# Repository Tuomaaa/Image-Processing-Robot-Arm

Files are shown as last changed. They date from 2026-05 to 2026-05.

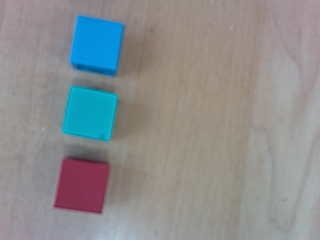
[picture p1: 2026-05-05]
Image&Videos/TestImage1.jpg

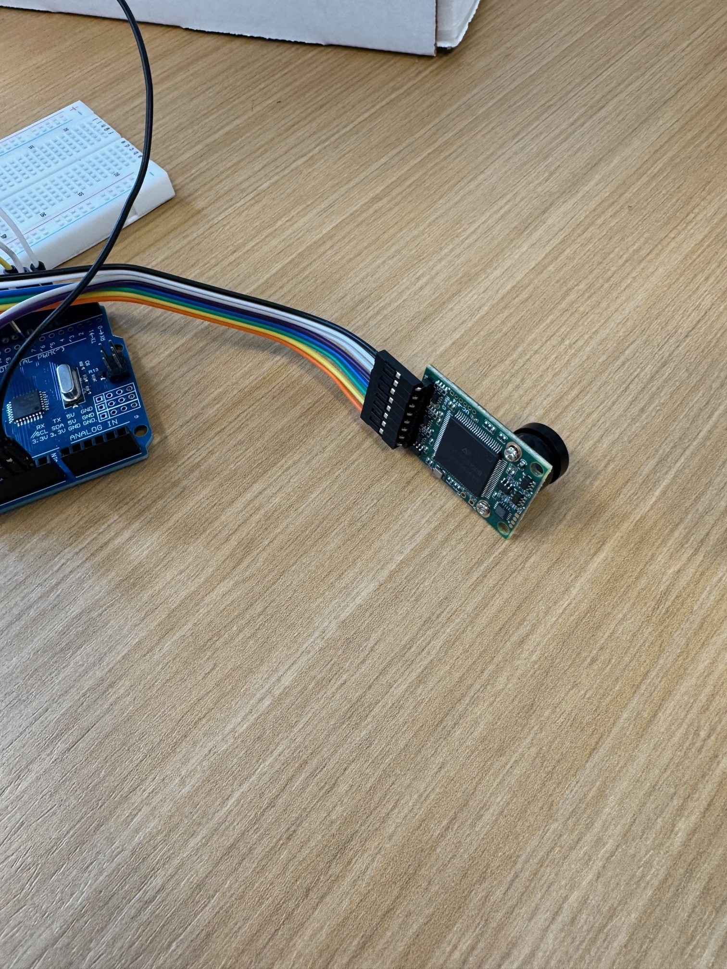
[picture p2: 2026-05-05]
Wiring/2.jpg

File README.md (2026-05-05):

This is 3d printed robot arm content for the image processing course
to create a block sorting project using MATLAB and an ArduCam. The arms was inspired by the following printable. 
https://www.printables.com/model/818975-compact-robot-arm-arduino-3d-printed/comments
Build Some Stuff8
Build Some Stuff
@buildsomestf_192457
Detailed Assembly Tutorial: https://youtu.be/AIsVlgopqJc Designed by Kelton.
https://www.youtube.com/watch?v=AIsVlgopqJc

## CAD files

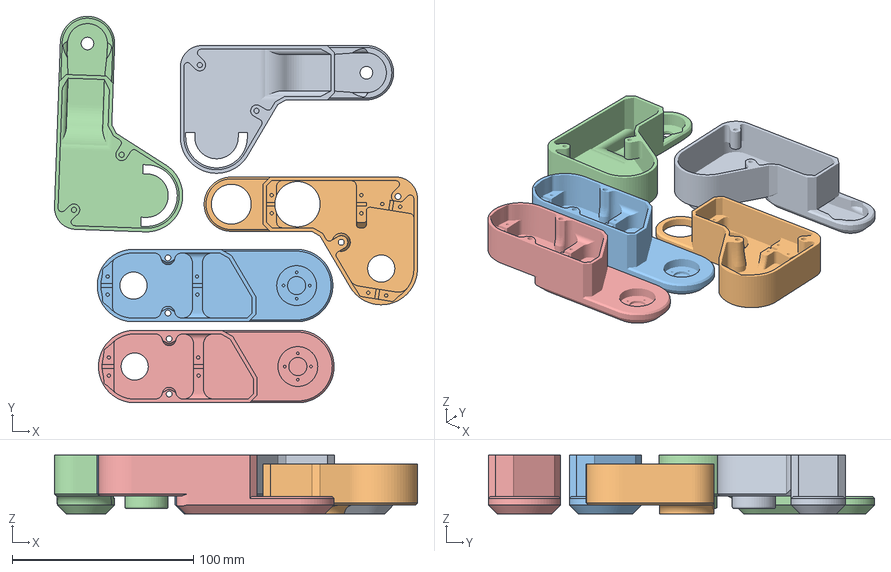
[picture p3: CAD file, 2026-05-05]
CAD/MainBody.3mf
200.3 x 213.1 x 32.5 mm
Forearm2.stl x 2
Forearm.stl
Upperarm.stl x 2

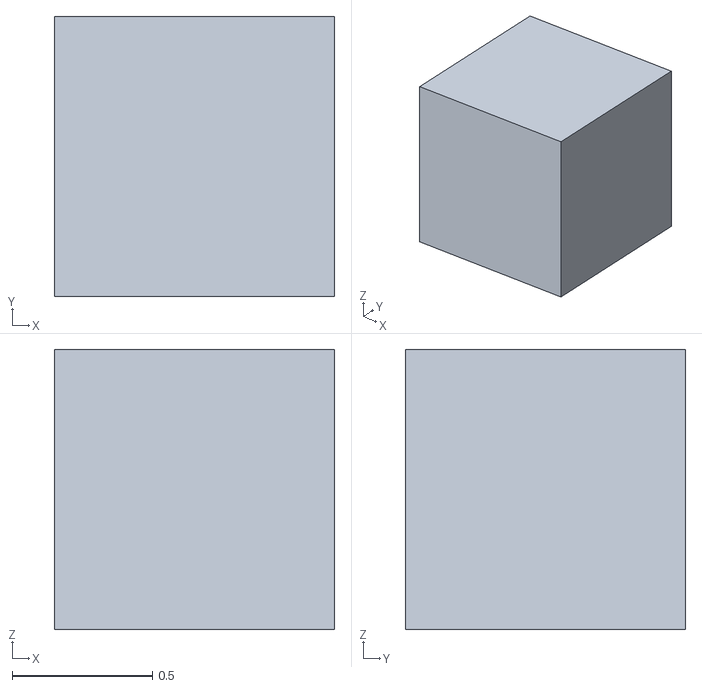
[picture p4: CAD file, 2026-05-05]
CAD/Monay_Square.stl
1.00 x 1.00 x 1.00

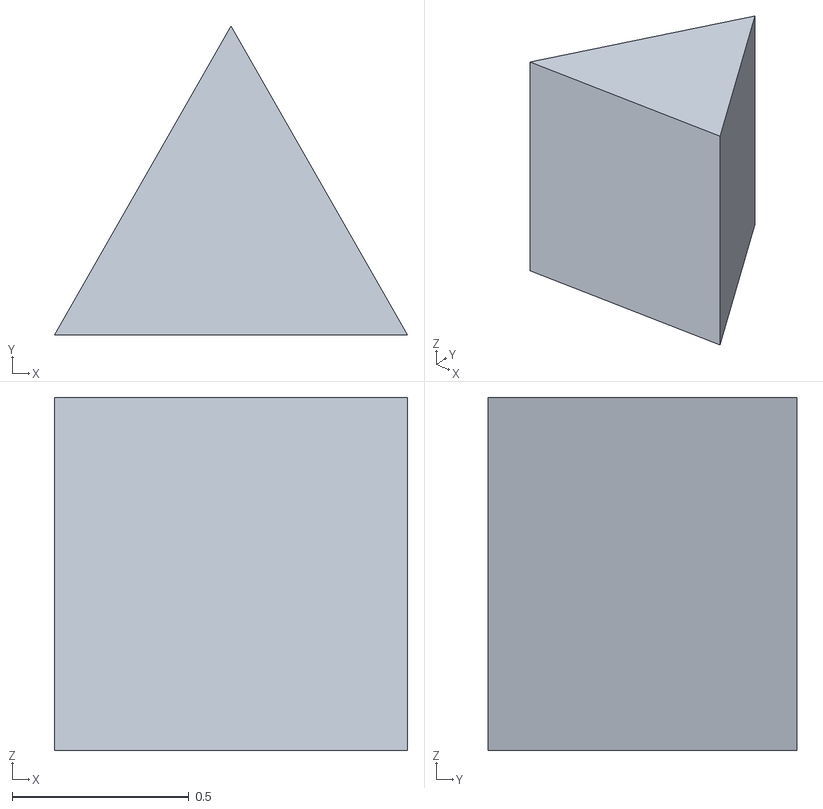
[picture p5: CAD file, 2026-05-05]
CAD/Monay_Triangle.stl
1.00 x 0.875 x 1.00

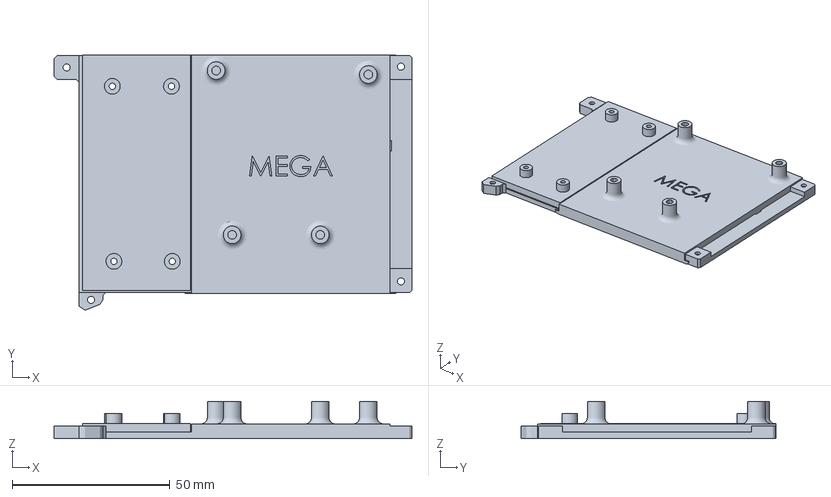
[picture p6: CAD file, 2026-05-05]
CAD/robotArm - MegaServo-Mount.3mf
113.5 x 81.0 x 11.7 mm

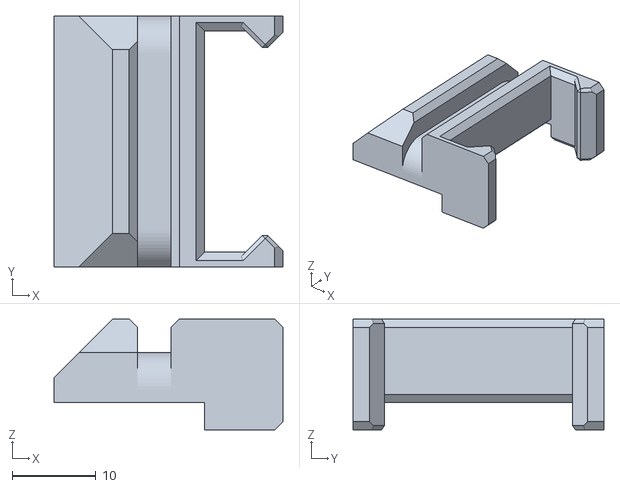
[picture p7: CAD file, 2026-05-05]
CAD/Gripper.stl
27.4 x 30.0 x 13.2

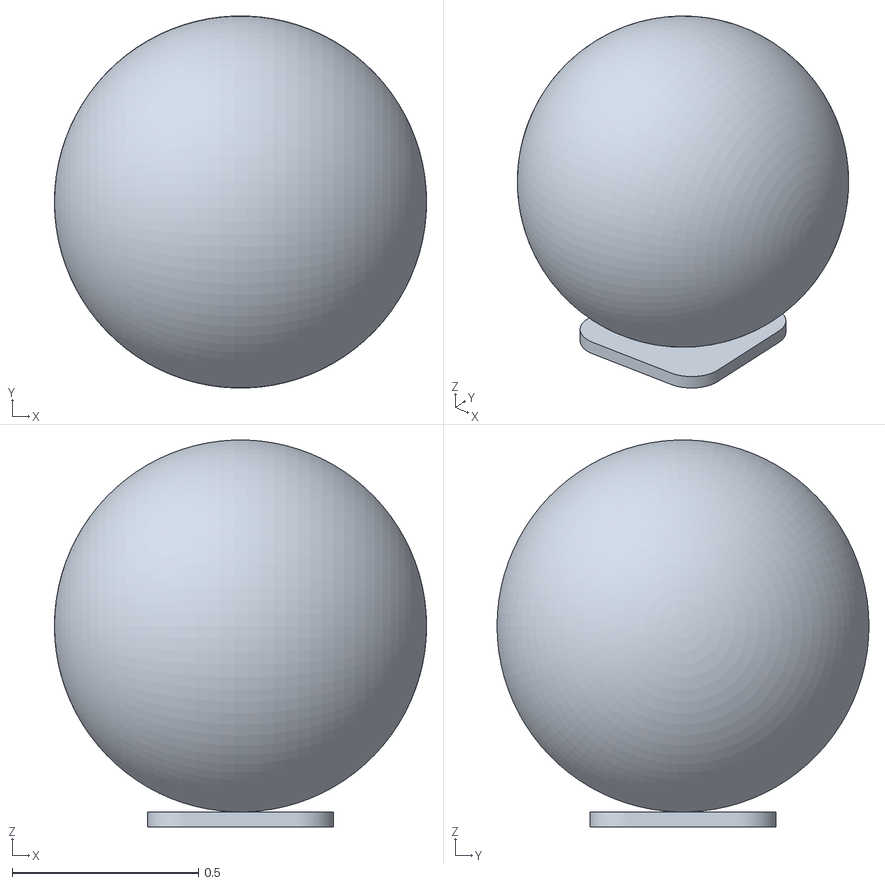
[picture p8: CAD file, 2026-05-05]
CAD/Monay_Sphere.stl
1.00 x 0.999 x 1.04

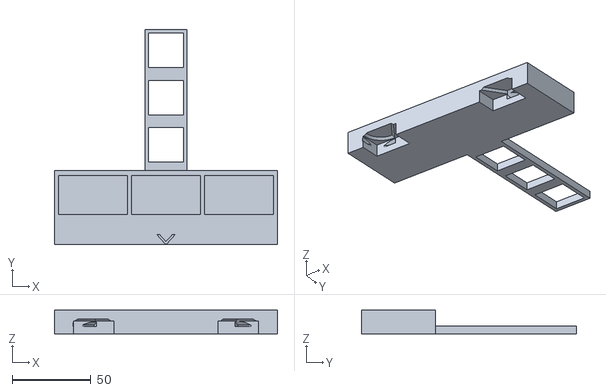
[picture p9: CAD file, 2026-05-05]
CAD/Object_Jig_V4.stl
142.0 x 137.2 x 15.0

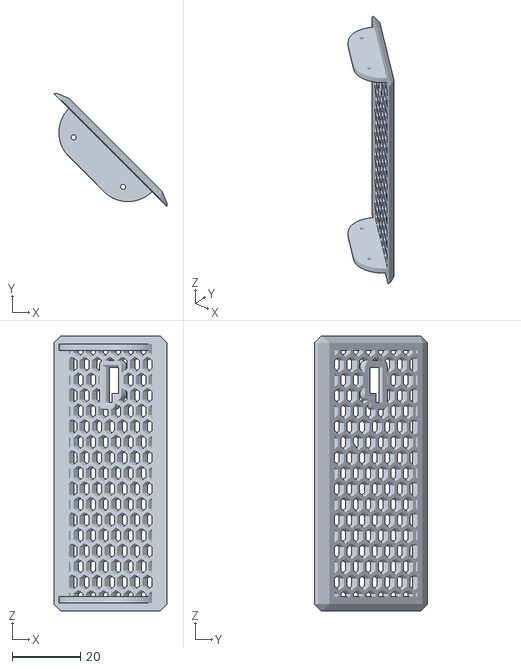
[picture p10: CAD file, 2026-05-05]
CAD/MB4.stl
33.0 x 33.0 x 80.5

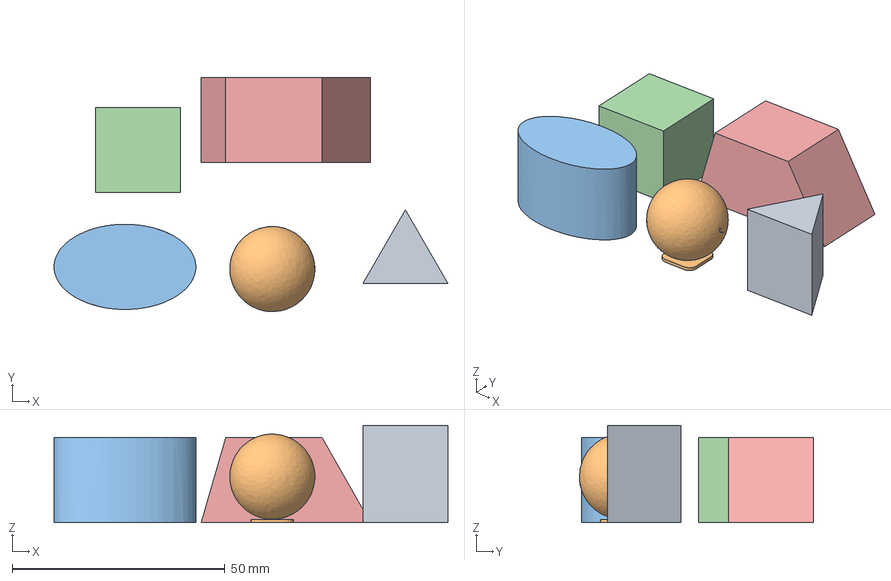
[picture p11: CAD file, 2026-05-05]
CAD/ImageProce_small.3mf
92.5 x 55.0 x 22.9 mm
ImageProce_small.stl
ImageProce_small (4).stl
ImageProce_small (3).stl
ImageProce_small (2).stl
ImageProce_small (1).stl

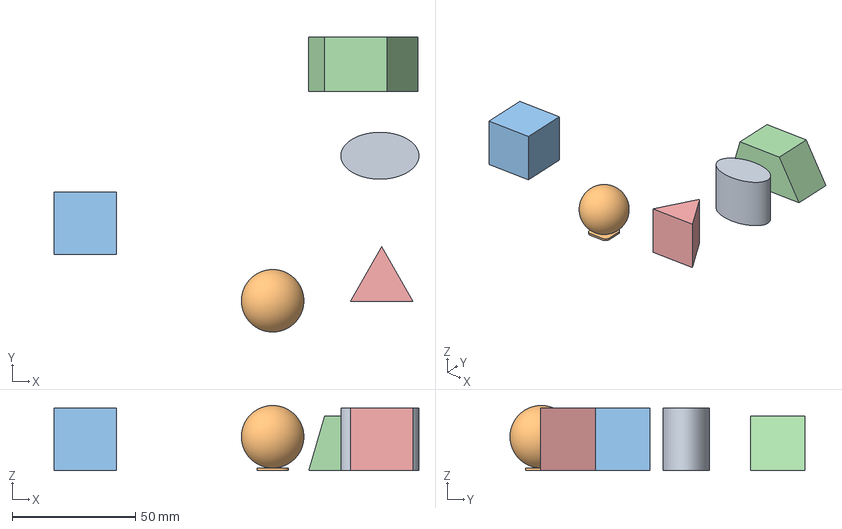
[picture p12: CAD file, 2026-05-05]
CAD/Monay_Ellipse.3mf
148.2 x 119.8 x 26.4 mm
Monay_Ellipse.stl
Monay_Sphere.stl
Monay_Square.stl
Monay_Trapezoid.stl
Monay_Triangle.stl

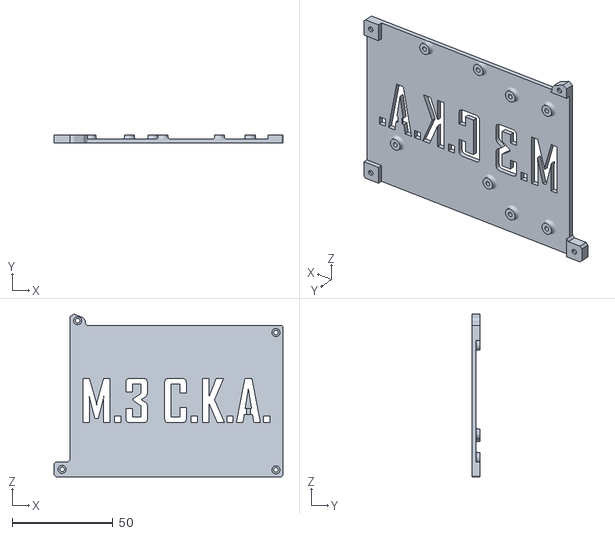
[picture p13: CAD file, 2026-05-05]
CAD/MB2.stl
113.5 x 4.00 x 80.7

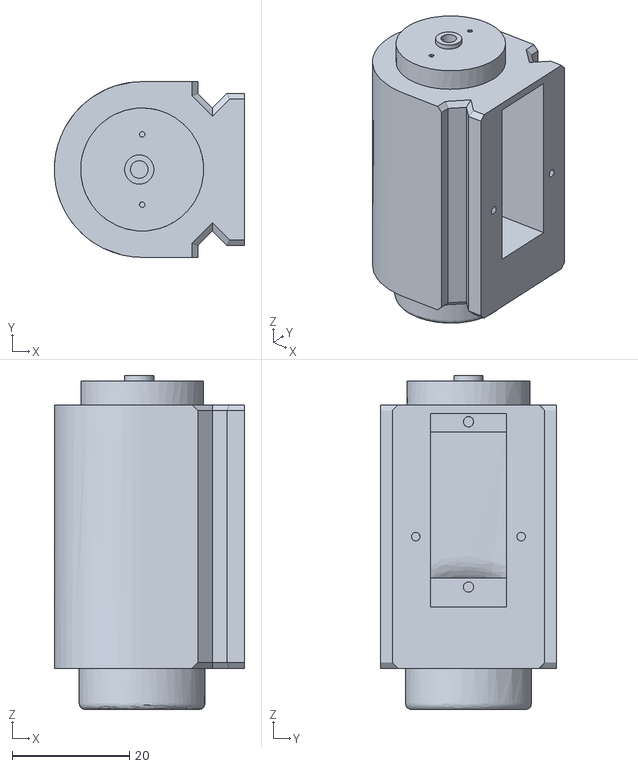
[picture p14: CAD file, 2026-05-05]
CAD/Modified Gripper2.stl
32.5 x 30.0 x 57.0

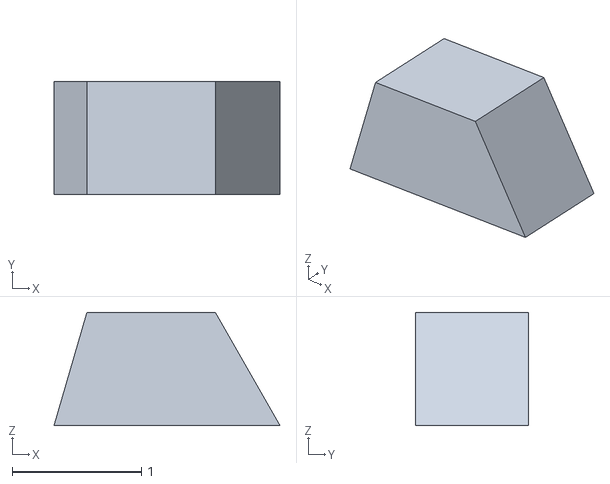
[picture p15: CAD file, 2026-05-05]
CAD/Monay_Trapezoid.stl
1.75 x 0.875 x 0.875

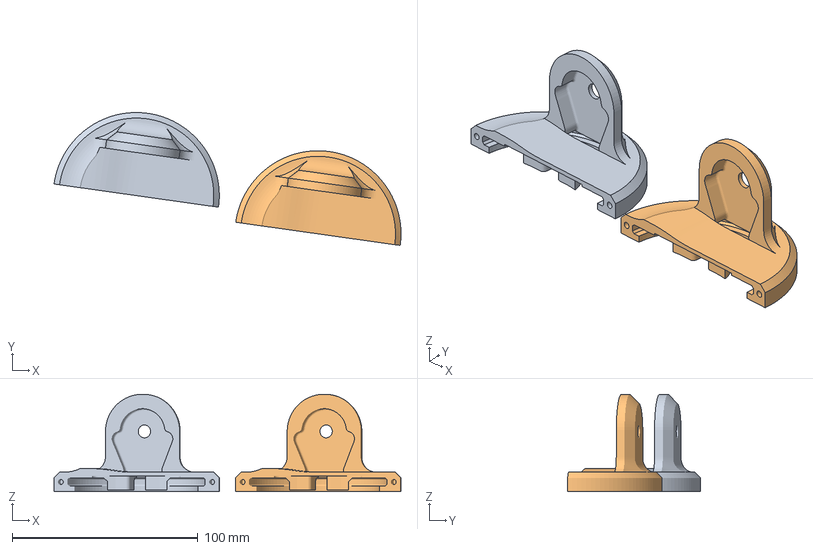
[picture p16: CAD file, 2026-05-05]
CAD/BaseHalf2.3mf
186.9 x 71.6 x 52.5 mm
BaseHalf2.stl x 2

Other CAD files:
CAD/WristModified.3mf
CAD/ForeArm_Set.stl
CAD/GripperCover.3mf
CAD/Upperarm.SLDPRT
CAD/BaseHalf.stl
CAD/BaseHalf2.stl
CAD/Base_Ring.SLDPRT
CAD/Base_Ring.stl
CAD/Forearm.SLDPRT
CAD/Forearm.STEP
CAD/Forearm.stl
CAD/Forearm2.SLDPRT
CAD/Forearm2.stl
CAD/G2.stl
CAD/GripperBod.stl
CAD/ImageProce_small (1).stl
CAD/ImageProce_small (2).stl
CAD/ImageProce_small (3).stl
CAD/ImageProce_small (4).stl
CAD/ImageProce_small.stl
CAD/MainBody.stl
CAD/Monay_Ellipse.stl
CAD/Object_Jig.stl
CAD/Object_Jig_V2b.stl
CAD/Object_Jig_V3.stl
CAD/Part Specs/Base_Ring.SLDDRW
CAD/Part Specs/Forearm.SLDDRW
CAD/Upperarm.3mf
CAD/Upperarm.stl
CAD/Upperarm2.stl
CAD/WristModified.stl
CAD/robotArm - MegaServo-Mount.stl

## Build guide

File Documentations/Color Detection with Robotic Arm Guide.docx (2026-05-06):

Introduction:

For this demonstration, there are 5 parts, with the goal to take a picture of a sequence of three colored blocks and sorting them using a robotic arm into various bins based on color. To do this, an Arduino code is used to take images using an Arducam connected to the Arduino UNO board, a MATLAB code is used to process these images and detect color patterns, followed by another Arduino code to receive the sequence from the MATLAB code and sort the blocks with the robotic arm. This guide will explain every step, from taking images, to calibrating the robot arm.

Steps Overview:

1. Take image using Arducam and Arduino program, Arducam host
2. Upload robotic arm program to Arduino, no external power supply connected
3. Use image in MATLAB program to send sequence to Arduino board, selecting the correct COM port for the Arduino
4. Disconnect Arduino from computer, and connect external power supply to Arduino
5. Reset Arduino, and allow it to sort

Part 1: Arduino UNO R3 Pinout for Arducam

To wire the Arducam to the Arduino, follow this pinout below:

Arducam Pins | Arduino UNO R3
CS | 7
MOSI | 11
MISO | 12
SCK | 13
GND | GND
VCC | 5V (Must be 5V)
SDA | A4
SCL | A5

Part 2: Image capture using Arducam

In order to take pictures using this camera, a specific program must be loaded onto the Arduino UNO, as well as a specific program that connects to the Arducam.

This YouTube video explains connecting to the camera very well.

Arducam Mini 2MP SPI Camera Module for Arduino Tutorial (https://www.youtube.com/watch?v=hybQpjwJ4aA)

This Website has the download for the Arduino Library.

GitHub - ArduCAM/Arduino: This is ArduCAM library for Arduino boards · GitHub (https://github.com/ArduCAM/Arduino)

The correct program will look like this:

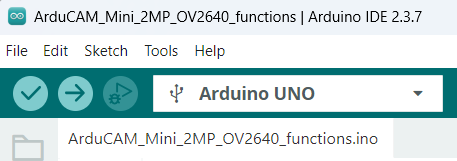
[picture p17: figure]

Figure 1: Arducam code

NOTE: Must change the baud rate in the program.

Line 42:

#if defined(__SAM3X8E__)

Wire1.begin();

Serial.begin(115200);

#else

Wire.begin();

Serial.begin(921600); → Serial.begin(115200);

Correct code:

#if defined(__SAM3X8E__)

Wire1.begin();

Serial.begin(115200);

#else

Wire.begin();

Serial.begin(115200);

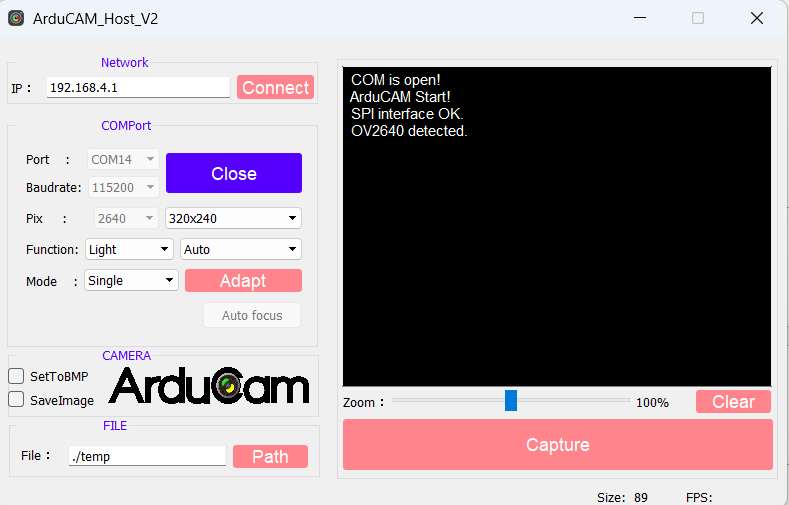
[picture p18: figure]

Figure 2: Arducam Host

Program should look similar to this with a different port.

Note: Must change baud rate in program to 115200.

After capturing image, save to folder with MATLAB file and rename to filename found in MATLAB script.

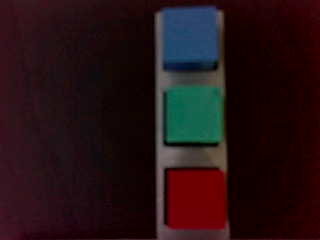
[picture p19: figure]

Figure 3: Example image for Arducam

The image above is a good example of how the blocks are arranged and how the image should appear. The sequence should be read top to bottom.

Part 3: MATLAB image processing

The next step is to use the MATLAB code to read the image, and process what the sequence is and send that to the Arduino program that controls the robot arm. The code for the robot arm is found in the next section, which must be uploaded to the robot before running the MATLAB code to have successful communication.

The code for MATLAB has many sections, so each section header will be explained now.

%% Image Capture via filename or webcamera

In this section, the image can either come from a file from an Arducam image, or from a connected webcam. When running this code, the name of the file must be changed to match the appropriate file from the picture taken.

%% Block Detection

Utilizes HSV to create certain cutoff values to detect what is a colored block and what is not a colored block. From this, a binary mask is created where the parts of a block are each set to 1, while everything else is set to 0.

Figure 4: Block detection

%% Color Detection

From each area of 1 value, the HSV values are measured, and then each pixel is classified as a blue, green, or red pixel and added to that count. Whichever counter has the highest value will determine the color of that block.

Figure 5: Color detection

%% Create sequence and print colors

After detecting the sequence, the color order will be printed with the appropriate sequence. All available ports will appear, allowing the user to time the associated index on the left to choose the port connected to the Arduino board. Typing 0 will cancel the program to make sure it cannot get stuck. In this section, the Arduino Serial Monitor must not be open as MATLAB requires this to connect to the board. After selecting the correct port, the sequence will be sent to the Arduino UNO.

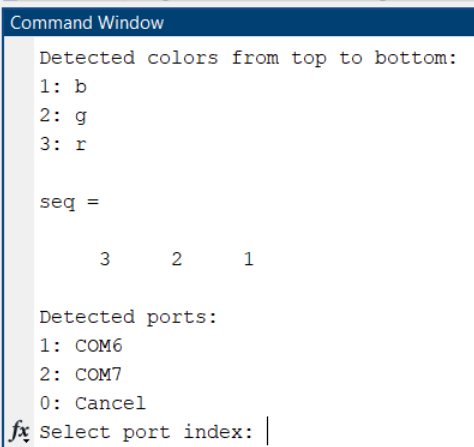
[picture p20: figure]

Figure 6: MATLAB command window for port selection

At this point, the MATLAB code is finished, and the robot is ready to sort. If the code is picking up shapes that are not the blocks, the HSV values must be tweaked to make sure the background is not too similar to the blocks. If the blocks are not being seen, then the HSV values must be changed to allow a wider range.

Part 4: Robot Arm Calibration

This part requires the most effort, as for each robot the values will be slightly different for the calibration. To start, the robot must be set appropriately with the jig, in a way that makes sure the jig is in line with the robot and as close to the base as possible.

Next, open the code called “RobotArmCalibration”, which allows a simple code that will set the location based on the values given, allowing a quick way to test new values. For each position, such as grabbing each block and placing each block, these values must be recorded and updated in the Arduino code “RobotArm_Pick_And_Place_MATLAB”.

Note: Never have external power supply or cable to computer connected at the same time. Power switch must be used to allow external power.

The next images will display how the values correspond to the arm movement.

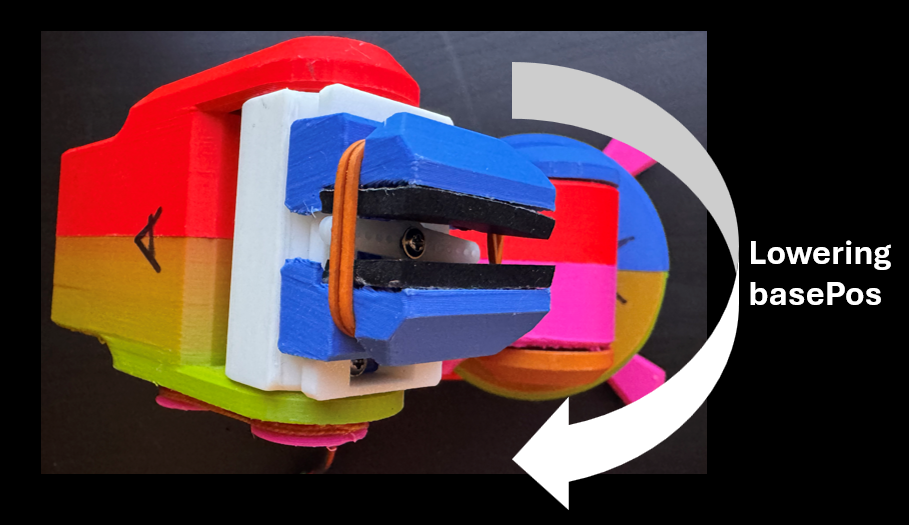
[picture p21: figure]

Figure 7: Base Position

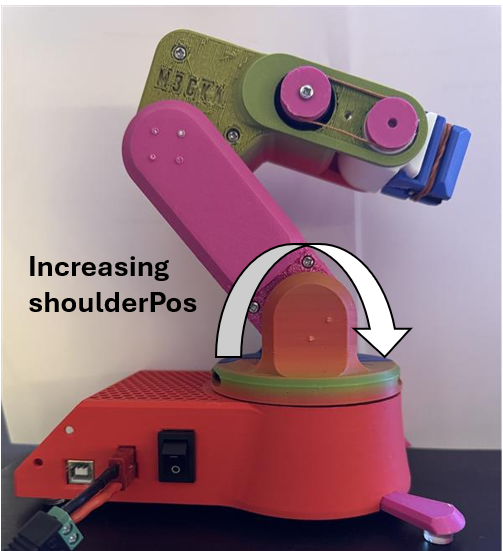
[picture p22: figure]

Figure 8: Shoulder Position

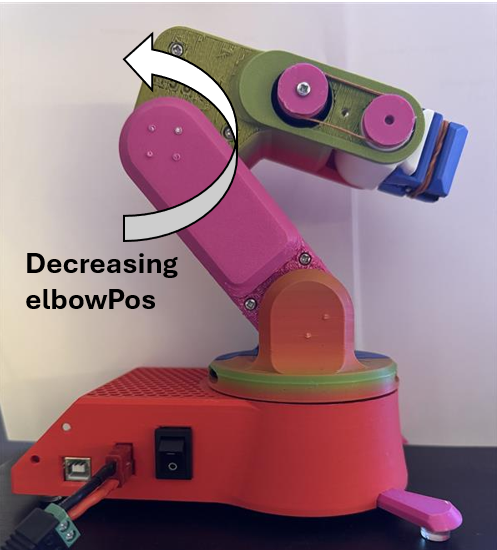
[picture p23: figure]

Figure 9: Elbow Position

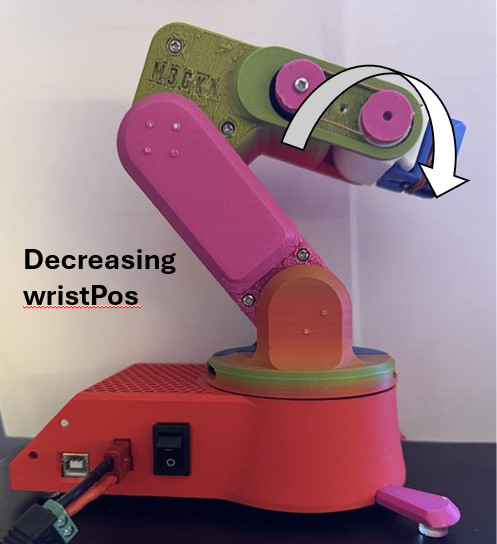
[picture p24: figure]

Figure 10: Wrist Position

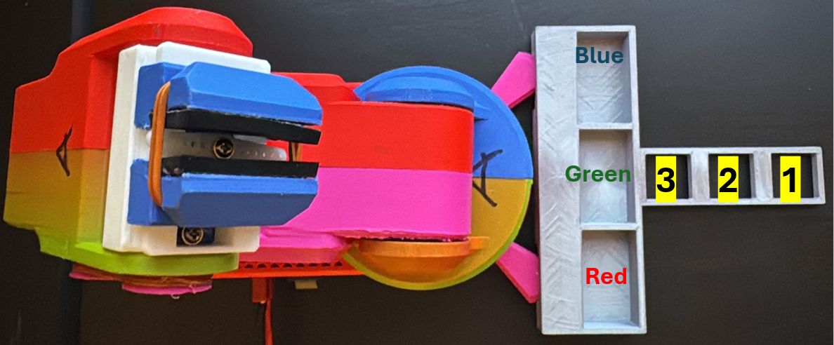
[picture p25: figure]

Figure 11: Jig location

Box 1 will be the first block grabbed, followed by box 2, and finally box 3.

The gripper should not need to be calibrated, the given values should work.

After calibrating and saving each of the variables, the code should be able to run a full sorting procedure.

Part 5: Robot Arm Sorting

After calibrating the arm, it is ready to receive data from the MATLAB code. Connect the robot to the computer, without the eternal power supply. Run the MATLAB code, and once it has sent to the robot, disconnect the Arduino from the computer. Connect the external power supply to the robot, and set the voltage to around 6 volts. Flip the power switch, and then press the reset button on the Arduino, and the robot should sort the blocks.

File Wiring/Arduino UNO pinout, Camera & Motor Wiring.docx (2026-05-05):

- MOSI (Master Out Slave In): Digital Pin 11
- MISO (Master In Slave Out): Digital Pin 12
- SCK (Serial Clock): Digital Pin 13
- ICSP
  - Top-Left: MISO
  - Middle-Right: MOSI
  - Bottom-Right: SCK
- SDA (Serial Data): Pin A4
- SCL (Serial Clock): Pin A5

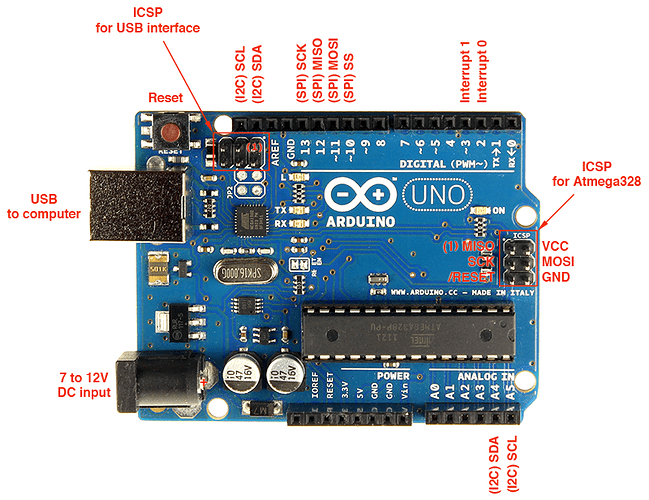
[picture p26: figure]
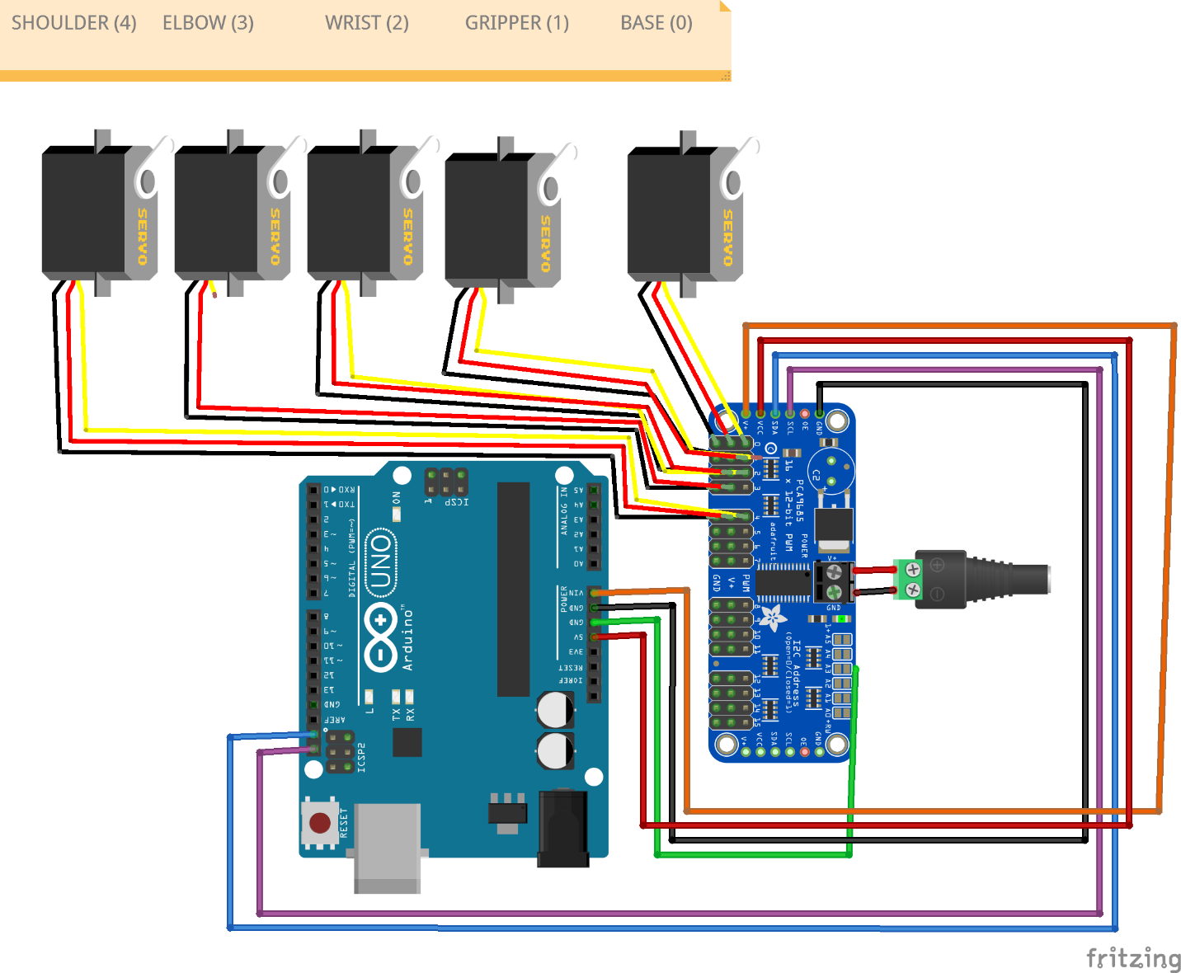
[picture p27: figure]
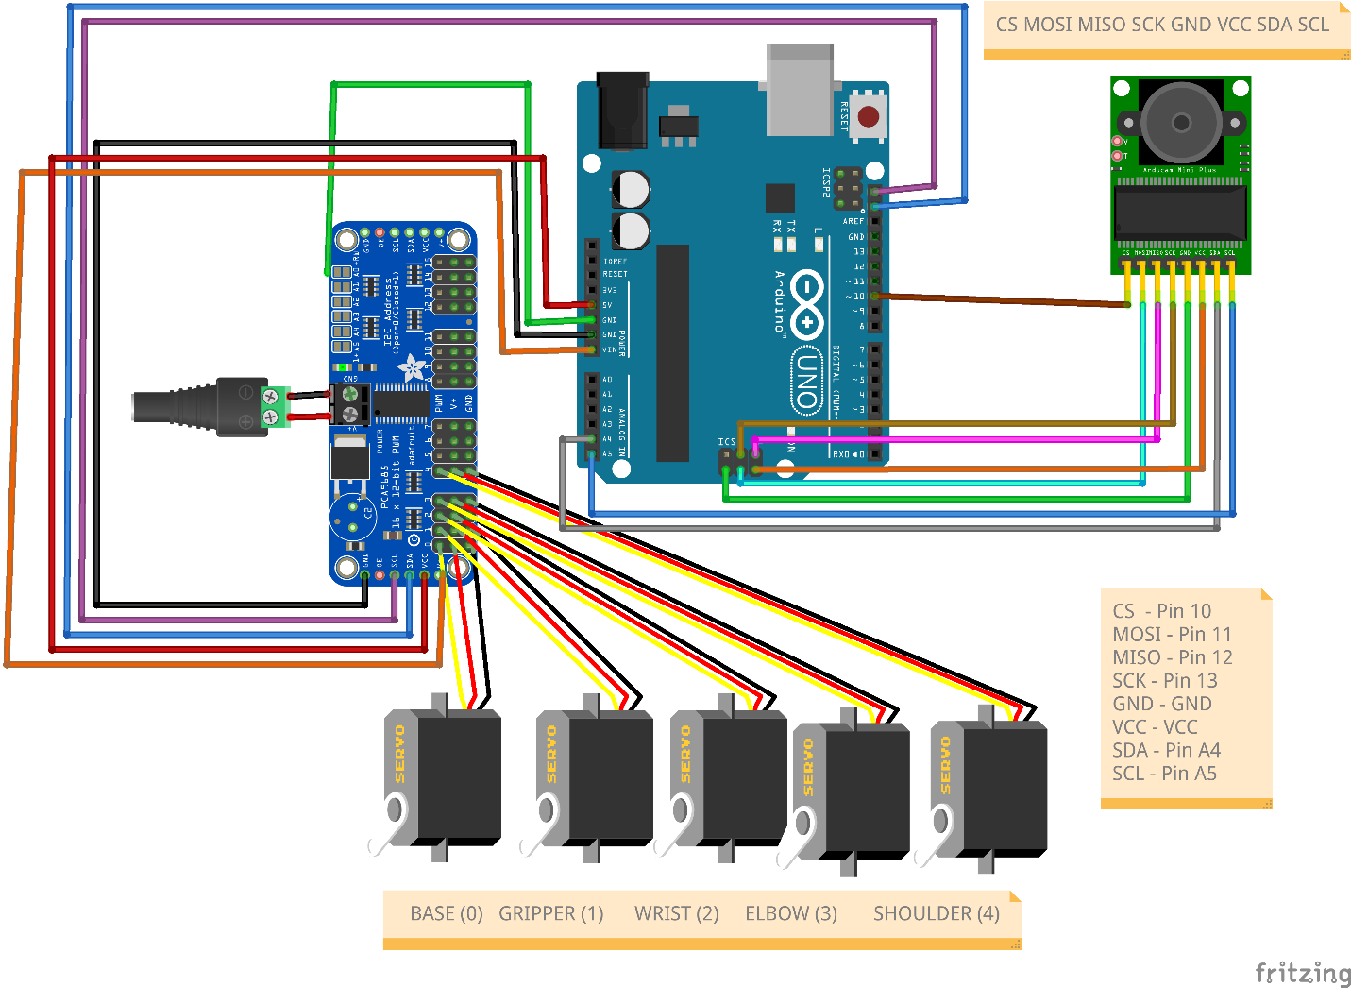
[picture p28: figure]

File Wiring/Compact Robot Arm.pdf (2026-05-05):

## Compact Robot Arm (Arduino) - 3D

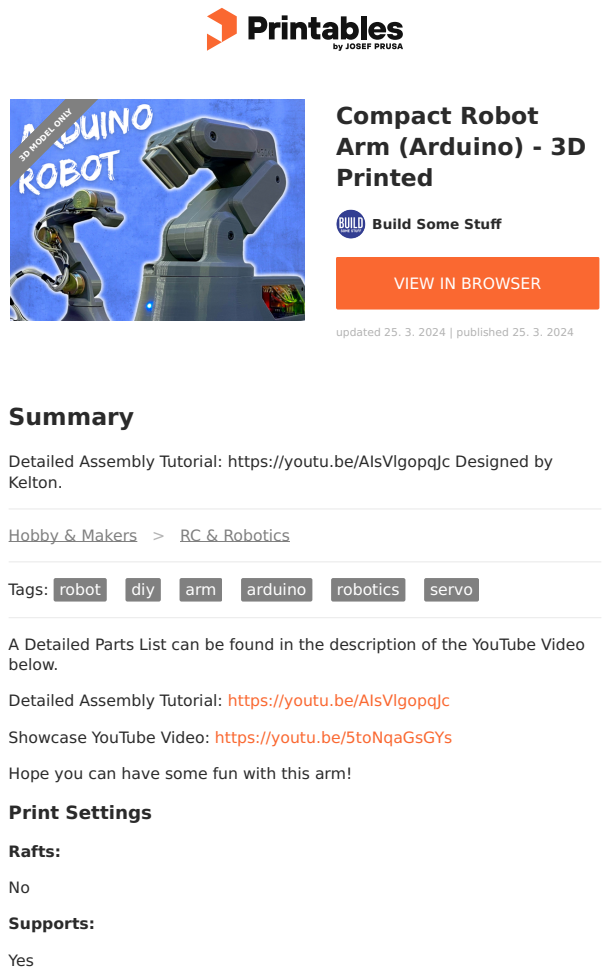
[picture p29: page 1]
Summary; Tags:; robot; diy; arm; arduino; robotics; servo; Rafts:; Supports:; Yes; Printed; updated 25. 3. 2024 | published 25. 3. 2024; 3D MODEL ONLY

Build Some Stuff (https://printables.com/@buildsomestf_1924578)

VIEW IN BROWSER (https://printables.com/model/818975-compact-robot-arm-arduino-3d-printed)

Detailed Assembly Tutorial: https://youtu.be/AIsVlgopqJc Designed by
Kelton.

Hobby & Makers (https://printables.com/model?categoryId=48) > RC & Robotics (https://printables.com/model?categoryId=64)

A Detailed Parts List can be found in the description of the YouTube Video
below.

Detailed Assembly Tutorial: https://youtu.be/AIsVlgopqJc

Showcase YouTube Video: https://youtu.be/5toNqaGsGYs

Hope you can have some fun with this arm!
Print Settings

## Model files

Resolution:

0.2

Infill:

Doesn’t Matter

Filament:

Doesn’t Matter

Category: Robotics

pot_b.stl

ns2.stl

m1.stl

g2.stl

mb2.stl

mb3.stl

f2.stl

mb1.stl

s2.stl

f2c.stl

mb1r.stl

pot_fa.stl

mb4.stl

pot_g.stl

g3.stl

g1.stl

s1.stl

b2.stl

ns1.stl

pot_rb.stl

b1.stl

g4.stl

f1.stl

m2.stl

pot_ma_2.stl

## Other files

Find source .stl files on Thingiverse.com (https://www.thingiverse.com/thing:6313449)

## License

This work is licensed under a
Creative Commons (4.0 International License)

Attribution—Noncommercial—No Derivatives (http://creativecommons.org/licenses/by-nc-nd/4.0/)

✖ | Sharing without ATTRIBUTION
✖ | Remix Culture allowed
✖ | Commercial Use
✖ | Free Cultural Works
✖ | Meets Open Definition

compact_robot_arm_code.ino

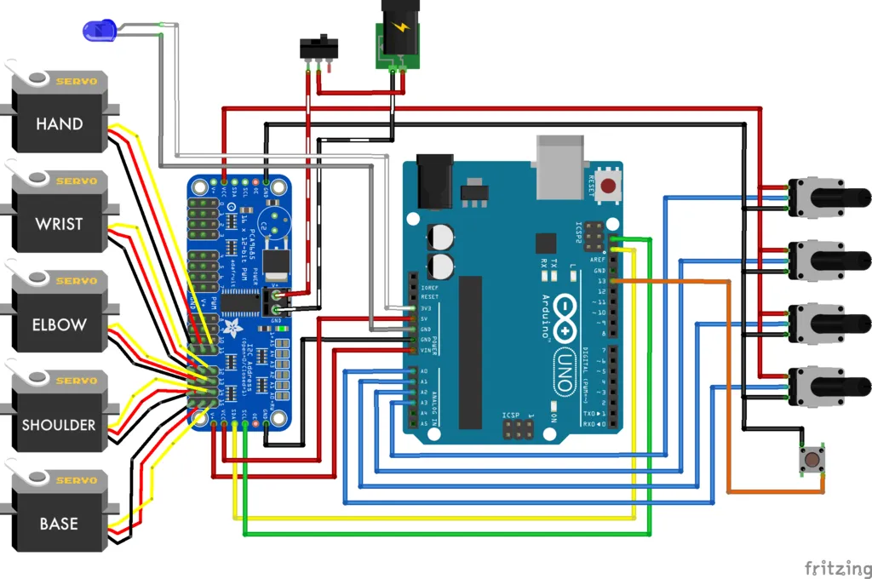
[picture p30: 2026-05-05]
Image&Videos/Compact Robot Arm Wiring Diagram.png

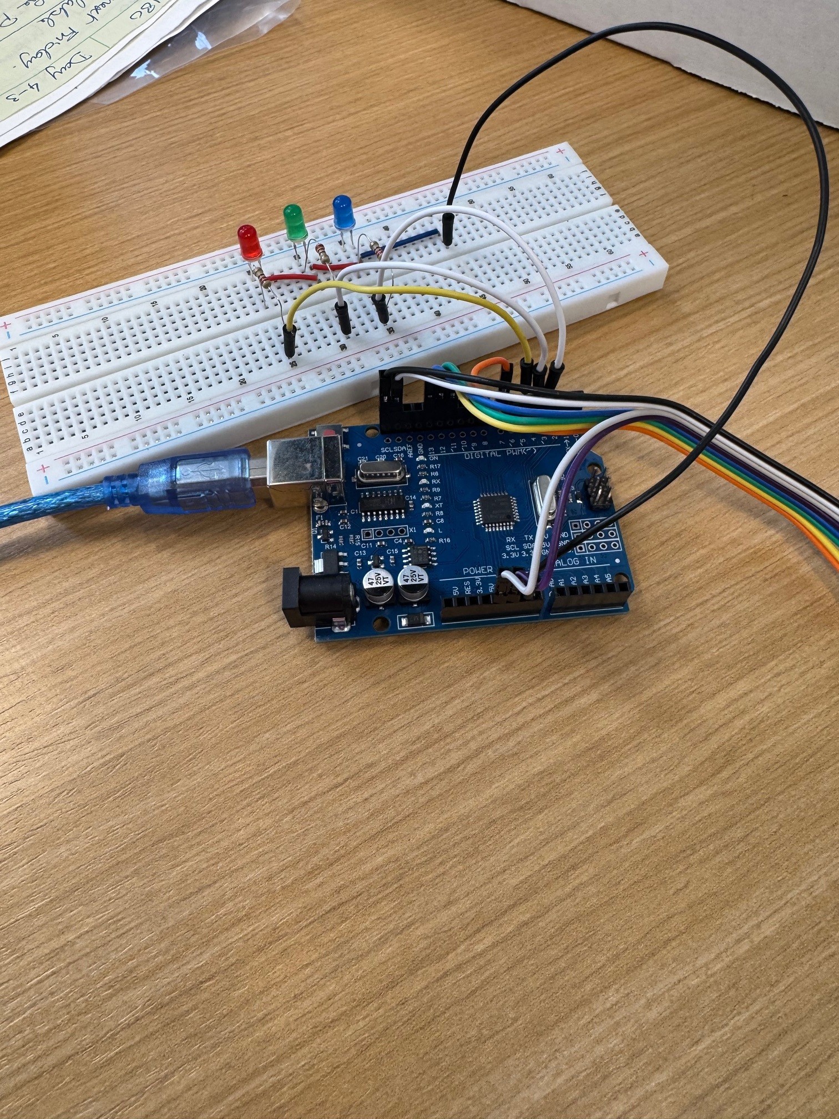
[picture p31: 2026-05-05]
Wiring/1.jpg

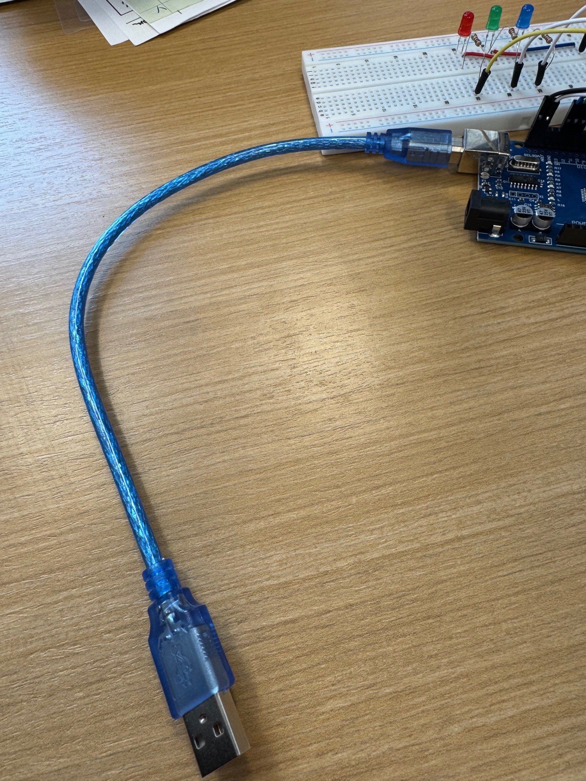
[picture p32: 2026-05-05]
Wiring/3.jpg

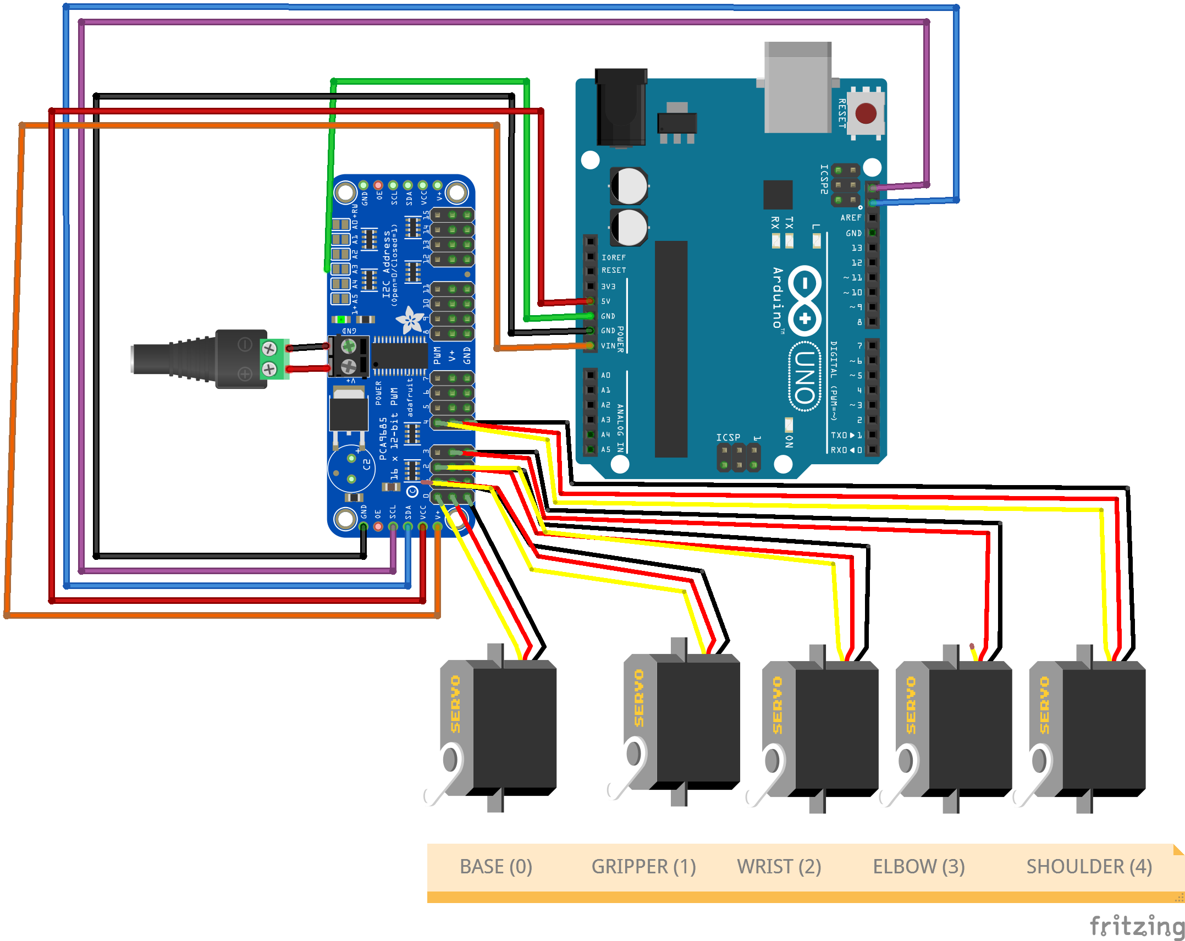
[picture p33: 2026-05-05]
Wiring/Robot Arm Wiring.png

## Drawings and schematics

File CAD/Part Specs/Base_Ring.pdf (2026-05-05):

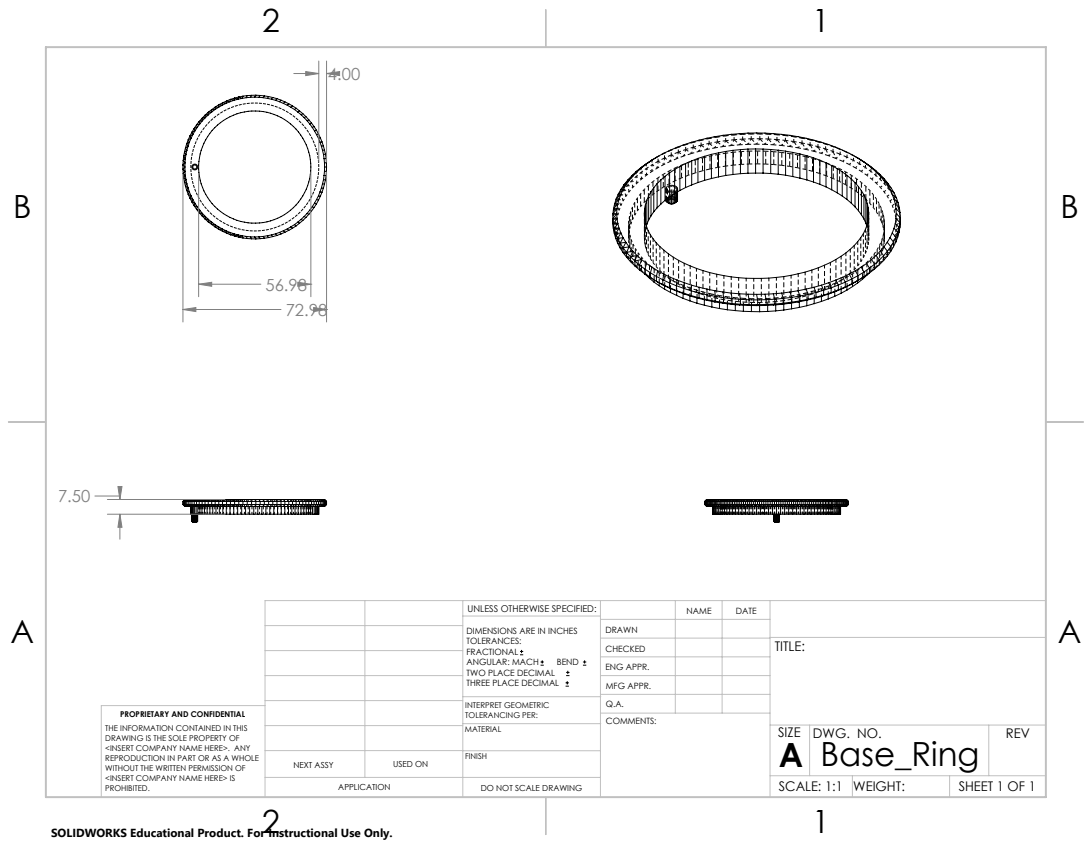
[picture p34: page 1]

UNLESS OTHERWISE SPECIFIED: | | NAME | DATE
DIMENSIONS ARE IN INCHES TOLERANCES: FRACTIONAL ANGULAR: MACH BEND TWO PLACE DECIMAL THREE PLACE DECIMAL | DRAWN

CHECKED | | | TITLE:

ENG APPR.
MFG APPR.

INTERPRET GEOMETRIC TOLERANCING PER: | Q.A.
MATERIAL | | SIZE A | DWG. NO. Base_Ring | REV

PROPRIETARY AND CONFIDENTIAL
THE INFORMATION CONTAINED IN THIS
DRAWING IS THE SOLE PROPERTY OF
<INSERT COMPANY NAME HERE>. ANY
REPRODUCTION IN PART OR AS A WHOLE
WITHOUT THE WRITTEN PERMISSION OF
<INSERT COMPANY NAME HERE> IS
PROHIBITED.

NEXT ASSY | USED ON | FINISH

APPLICATION | DO NOT SCALE DRAWING | | SCALE: 1:1 | WEIGHT: | SHEET 1 OF 1

SOLIDWORKS Educational Product. For Instructional Use Only.

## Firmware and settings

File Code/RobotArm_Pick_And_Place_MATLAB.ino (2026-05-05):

/*************************************************** 
CAB 4/1/26
RobotArm-Pick-And-Place_MATLAB.ino
This code moves the 3d printed 5DOF robot to pick up a red, green and blue cube from one of three pick up locations
to a place location in front of the robot
5 DOF Robot (base - 0, shoulder - 4, elbow - 3, wrist - 2, gripper - 1)
  3 values received from MATLAB
    cube locations are
      1st number - location of red cube goes to place 1 (robot's right), place1() function
      2nd number - location of green cube goes to place 2 (robot's front),place2() function
      3rd number - location of blue cube goes to place 3 (robot's left), place3() function

    Pick location
      1 - top (furthest from robot), pick1() function 
      2 - middle - pick 2, pick2() function
      3 - bottom (closest to robot), pick3() function 

  */

#include <Wire.h>                                         //this library allows I2C communicaton for the servo driver board and arducam
#include <Adafruit_PWMServoDriver.h>                      //servo motor driver library
#include <EEPROM.h>                                       //voltatile memory library
Adafruit_PWMServoDriver pwm = Adafruit_PWMServoDriver();  //instance of servo motor driver

struct Data {  //data structure to hold color position data from MATLAB
  int color1;
  int color2;
  int color3;
};

Data myData;          //instance of data structure current data from matLab
Data newValue;        //new data from MATLAB
int EEPROM_ADDR = 0;  //address to store color position data in volatile memory
int positions[3];     //variable to hold color cube position data

//servo motor and other global variables
#define SERVO_FREQ 50     // Analog servos run at ~50 Hz updates
#define baudrate 115200   //servo communication baudrate
#define oscFreq 27000000  //oscilator frequency
#define pauseTime 1000    //pause between test cycles
#define maxSpeed 10       //maximum robot speed
int speed = 6;            //speed is an integer between 0 and 10, increase to speed up robot
#define blocks 3          //number of blocks to sort

//hardware connections
#define base 0      // robot base = 0
#define shoulder 4  // robot shoulder = 1
#define elbow 3     // robot elbow = 3
#define wrist 2     // robot wriset = 4
#define gripper 1   // robot gripper = 5

/**********MOTOR POSITIONS FOR HOMING AND PICK AND PLACE POSITIONS - can eventyally move to tab or header 
calibrate these values to work best for your robot*/
#define BUSMIN 600    // base minimum position (far right)
#define BUSMAX 2400   // base maximum position (far left)
#define BUSHome 1500  //base home position (middle)
int BPos = BUSHome;   //current base position

#define BPlace1a 1200  //base place 1 position a (right)
#define BPlace2a 1500  //base place 2 position a (center)
#define BPlace3a 1900  //base place 3 position a (lefy)

#define SUSMIN 800    //shoulder min (back)
#define SUSMAX 2000   //shoulder max (forward)
#define SUSHome 1000  //shoulder home (middle)
int SPos = SUSHome;   //current shoulder position

#define SPick3a 1800  //shoulder pick 3a (in)
#define SPick3b 2100  //shoulder pick 3b (way in)

#define SPick2a 1800  //shoulder pick 2a (in)
#define SPick2b 2200  //shoulder pick 2b ( way in)

#define SPick1a 2000  //shoulder pick 1a (in)
#define SPick1b 2200  //shoulder pick 1b (way in)

#define SPlace1a 1300  //shoulder place 1a (in)
#define SPlace1b 1700  //shoulder place 1b (way in)

#define SPlace2a 1300  //shoulder place 2a (in)
#define SPlace2b 1700  //shoulder place 2b (way in)

#define SPlace3a 1300  //Shoulder place 3a (in)
#define SPlace3b 1800  //Shoulder place 3a (way in)

#define EUSMIN 800    //elbow min (out)
#define EUSMAX 2000   //elbow max (in)
#define EUSHome 1500  //elbow home (middle)
int EPos = EUSHome;   //current elbow position

#define EPick1a 1000  //shoulder pick 1a (in)
#define EPick2a 1200  //shoulder pick 2a (in)
#define EPick3a 1300  //shoulder pick 3a (in)

#define EPlace1a 1600  //shoulder place 1a (in)
#define EPlace2a 1600  //shoulder place 2a (in)
#define EPlace3a 1600  //shoulder place 3a (in)

#define WUSMIN 600    // wristmin (far in)
#define WUSMAX 2000   // wrist max (far out)
#define WUSHome 1000  //wristhome (mid)
int WPos = WUSHome;   //current wrist position

#define WPick1 1000  //wrist (mid)
#define WPick2 1000  //wrist (mid)
#define WPick3 1000  //wrist (mid)

#define WPlace1 1000  //wrist (mid)
#define WPlace2 1000  //wrist (mid)
#define WPlace3 1000  //wrist (mid)

#define GUSMIN 600   //gripper vertical
#define GUSMAX 1300  //gripper horizontal
#define GUSHome 600  //gripper home
int GPos = GUSHome;  //current gripper positiion

#define GOpen 1200  //gripper open
#define GClose 600  //gripper close

//code that runs only once
void setup() {
  Serial.begin(baudrate);               //start serial communication
  pinMode(LED_BUILTIN, OUTPUT);         //LED on pin 13 on Arduino to blink with position data
  pwm.begin();                          //start servo motor driver board
  pwm.setOscillatorFrequency(oscFreq);  //set servo motor oscillator frequency
  pwm.setPWMFreq(SERVO_FREQ);           // Analog servos run at ~50 Hz updates
  delay(1000);

  // Restore last saved value
  EEPROM.get(EEPROM_ADDR, myData);
  Serial.print("color position data: ");
  Serial.print(myData.color1);
  Serial.print(myData.color2);
  Serial.println(myData.color3);

  /************** UNCOMMENT FUNCTIONS FOR TESTING EACH MOTOR DURING CALIBRATIONT*/
  // Serial.println("Move to Home");
  // robotHoming();
  // delay(pauseTime);
  // Serial.println("Move to Pick 1");
  // delay(pauseTime);
  // pick1();
  // delay(pauseTime);
  // Serial.println("Move to Place 1");
  // place1();
  // delay(pauseTime);
  // Serial.println("Move to Pick 2");
  // pick2();
  // delay(pauseTime);
  // Serial.println("Move to Place 2");
  // place2();
  // delay(pauseTime);
  // Serial.println("Move to Pick 3");
  // pick3();
  // delay(pauseTime);
  // Serial.println("Move to Place 3");
  // place3();
}

//code that runs indefinitely
void loop() {
  matlabSequence();  //read position data from MATLAB
  printPositions();  //print position data to serial monitor
  LEDBlink();        //blink position data on LED
  delay(100);
  if (positions[0] != 0 && positions[1] != 0 && positions[2] != 0) {
    for (int i = 0; i < blocks; i++) {
      Serial.println("start moving cubes");
      switch (positions[i]) {
        //base - 0, shoulder - 4, elbow - 3, wrist - 2, gripper - 1
        case 1:  //base
          pick1();
          break;
        case 2:  //gripper
          pick2();
          break;
        case 3:  //wrist
          pick3();
          break;
      }
      switch (i) {
        //base - 0, shoulder - 4, elbow - 3, wrist - 2, gripper - 1
        case 0:  //base
          place1();
          break;
        case 1:  //gripper
          place2();
          break;
        case 2:  //wrist
          place3();
          break;
      }
    }
    //finished sorting, stoop loop
    while (1) {};
  }  //end if condition
  else {
    Serial.println("no cube position data received");
  }
}

//read cube position data from MATLAB

void matlabSequence() {
  Serial.println("MATLAB SEQUENCE");
  if (Serial.available() >= 3) {
    Serial.print("Incoming: ");
    newValue.color1 = Serial.parseInt();
    newValue.color2 = Serial.parseInt();
    newValue.color3 = Serial.parseInt();
    Serial.print(newValue.color1);
    Serial.print(newValue.color2);
    Serial.println(newValue.color3);
    if (isDifferent(newValue, myData) && isNonZero(newValue)) {
      myData = newValue;
      Serial.print("Stored");
      Serial.print(myData.color1);
      Serial.print(myData.color2);
      Serial.println(myData.color3);
      EEPROM.put(EEPROM_ADDR, myData);
    } else {
      Serial.println("no new data received");
    }
  }  //serial available
}

bool isDifferent(Data a, Data b) {
  return (a.color1 != b.color1) || (a.color2 != b.color2) || (a.color3 != b.color3);
}

bool isNonZero(Data a) {
  return (a.color1 > 0) && (a.color2 > 0) && (a.color3 > 0);
}

//print cube position data to serial monitor
void printPositions() {
  String colors[3] = { " red: ", " green: ", " blue: " };
  positions[0] = myData.color1;
  positions[1] = myData.color2;
  positions[2] = myData.color3;
  for (int i = 0; i < 3; i++) {
    Serial.print(colors[i]);
    Serial.print(positions[i]);
  }
  Serial.println();
}

// Simple function to cause LED to blink at amount based on sequence
void LEDBlink() {
  int pos[3] = { myData.color1, myData.color2, myData.color3 };
  for (int i = 0; i < 3; i++) {
    if (pos[i] != 0) {
      for (int k = 0; k < pos[i]; k++) {
        digitalWrite(LED_BUILTIN, HIGH);
        delay(100);
        digitalWrite(LED_BUILTIN, LOW);
        delay(100);
      }
      delay(400);
    } else {
      digitalWrite(LED_BUILTIN, LOW);
    }
  }
  delay(1000);
}

/***********************************************************************************/
//move the robot arm to a location at a given speed
void moveSpeed(int joint, int location, int spd) {
  int steps = spd;  //movement steps, make this value 1 to 10 to modify speed, increase to speed up robot
  int current;      //holds the current position of the joint passed to the function
  int start;        //holds i loop variable start value
  // Serial.print("joint: ");
  // Serial.print(joint);
  // Serial.print(" location: ");
  // Serial.print(location);
  // Serial.print(" speed: ");
  // Serial.print(spd);
  // Serial.print(" delay ");
  // Serial.println(10 * (maxSpeed - spd));

  switch (joint) {
    //base - 0, shoulder - 4, elbow - 3, wrist - 2, gripper - 1
    case base:  //base
      current = BPos;
      break;
    case gripper:  //gripper
      current = GPos;
      break;
    case wrist:  //wrist
      current = WPos;
      break;
    case elbow:  //elbow
      current = EPos;
      break;
    case shoulder:  //shoulder
      current = SPos;
      break;
  }

  start = current;  //set the i start value to current joint position
  if (spd > 0) {
    if (location > start) {
      for (int i = start; i <= location; i = i + steps) {
        pwm.writeMicroseconds(joint, i);  //pin 0
        delay(maxSpeed - spd);            //delay movements by robot speed
        //Serial.println(i);
      }
    } else {
      for (int i = start; i >= location; i = i - steps) {
        pwm.writeMicroseconds(joint, i);  //pin 0
        delay(maxSpeed - spd);            //delay movements by robot speed
        //Serial.println(i);
      }
    }
    setCurrent(joint, location);  //set joint current positionto final value
  }
}

//set robot joint current position
void setCurrent(int joint, int pos) {
  switch (joint) {
    //base - 0, shoulder - 4, elbow - 3, wrist - 2, gripper - 1
    case base:  //base
      BPos = pos;
      break;
    case gripper:  //gripper
      GPos = pos;
      break;
    case wrist:  //wrist
      WPos = pos;
      break;
    case elbow:  //elbow
      EPos = pos;
      break;
    case shoulder:  //shoulder
      SPos = pos;
      break;
  }
}

//set robot to start position
void robotHoming() {
  Serial.println("homing: move base home");
  moveSpeed(base, BUSHome, speed);
  setCurrent(base, BUSHome);  //set joint current positionto final value
  delay(pauseTime);
  //Serial.println("homing: move shoulder home");
  moveSpeed(shoulder, SUSHome, speed);
  setCurrent(shoulder, SUSHome);  //set joint current positionto final value
  delay(pauseTime);
  //Serial.println("homing: move elbow home");
  moveSpeed(elbow, EUSHome, speed);
  setCurrent(elbow, EUSHome);  //set joint current positionto final value
  delay(pauseTime);
  //Serial.println("homing: move wrist home");
  moveSpeed(wrist, WUSHome, speed);
  setCurrent(wrist, WUSHome);  //set joint current positionto final value
  delay(pauseTime);
  //Serial.println("homing: move gripper home");
  moveSpeed(gripper, GUSHome, speed);
  setCurrent(gripper, GUSHome);  //set joint current positionto final value
}

//pick up object from position 1
void pick1() {
  Serial.println("pick up from position1");
  //Serial.println("pick1: move base");
  delay(pauseTime);
  moveSpeed(base, BUSHome, speed);
  setCurrent(base, BUSHome);  //set joint current positionto final value
  delay(pauseTime);
  //Serial.println("pick1: move elbow");
  moveSpeed(elbow, EPick1a, speed);
  setCurrent(elbow, EPick1a);  //set joint current positionto final value
  delay(pauseTime);
  //Serial.println("pick1: move shoulder");
  moveSpeed(shoulder, SPick1a, speed);
  setCurrent(shoulder, SPick1a);  //set joint current positionto final value
  delay(pauseTime);
  //Serial.println("pick1: move gripper");
  moveSpeed(gripper, GOpen, speed);
  setCurrent(gripper, GOpen);  //set joint current positionto final value
  delay(pauseTime);
  //Serial.println("pick1: move wrist");
  moveSpeed(wrist, WPick1, speed);
  setCurrent(wrist, WPick1);  //set joint current positionto final value
  delay(pauseTime);
  //Serial.println("pick1: move shoulder");
  moveSpeed(shoulder, SPick1b, speed);
  setCurrent(shoulder, SPick1b);  //set joint current positionto final value
  delay(pauseTime);
  //Serial.println("pick1: move gripper");
  moveSpeed(gripper, GClose, speed);
  setCurrent(gripper, GClose);  //set joint current positionto final value
  delay(pauseTime);
  //Serial.println("pick1: move shoulder");
  moveSpeed(shoulder, SUSHome, speed);
  setCurrent(shoulder, SUSHome);  //set joint current positionto final value
  delay(pauseTime);
  //Serial.println("pick1: move elbow");
  moveSpeed(elbow, EUSHome, speed);
  setCurrent(elbow, EUSHome);  //set joint current positionto final value
}

//pick up object from position 2
void pick2() {
  Serial.println("pick up from position2");
  //Serial.println("pick2: move base");
  delay(pauseTime);
  moveSpeed(base, BUSHome, speed);
  setCurrent(base, BUSHome);  //set joint current positionto final value
  delay(pauseTime);
  //Serial.println("pick2: move elbow");
  moveSpeed(elbow, EPick2a, speed);
  setCurrent(elbow, EPick2a);  //set joint current positionto final value
  delay(pauseTime);
  //Serial.println("pick2: move shoulder");
  moveSpeed(shoulder, SPick2a, speed);
  setCurrent(shoulder, SPick2a);  //set joint current positionto final value
  delay(pauseTime);
  //Serial.println("pick2: move gripper");
  moveSpeed(gripper, GOpen, speed);
  setCurrent(gripper, GOpen);  //set joint current positionto final value
  delay(pauseTime);
  //Serial.println("pick2: move wrist");
  moveSpeed(wrist, WPick1, speed);
  setCurrent(wrist, WPick1);  //set joint current positionto final value
  delay(pauseTime);
  //Serial.println("pick2: move shoulder");
  moveSpeed(shoulder, SPick2b, speed);
  setCurrent(shoulder, SPick2b);  //set joint current positionto final value
  delay(pauseTime);
  //Serial.println("pick2: move gripper");
  moveSpeed(gripper, GClose, speed);
  setCurrent(gripper, GClose);  //set joint current positionto final value
  delay(pauseTime);
  //Serial.println("pick2: move shoulder");
  moveSpeed(shoulder, SUSHome, speed);
  setCurrent(shoulder, SUSHome);  //set joint current positionto final value
  delay(pauseTime);
  //Serial.println("pick2: move elbow");
  moveSpeed(elbow, EUSHome, speed);
  setCurrent(elbow, EUSHome);  //set joint current positionto final value
}

//pick up object from position 3
void pick3() {
  Serial.println("pick up from position3");
  //Serial.println("pick3: move base");
  delay(pauseTime);
  moveSpeed(base, BUSHome, speed);
  setCurrent(base, BUSHome);  //set joint current positionto final value
  delay(pauseTime);
  //Serial.println("pick3: move elbow");
  moveSpeed(elbow, EPick3a, speed);
  setCurrent(elbow, EPick3a);  //set joint current positionto final value
  delay(pauseTime);
  //Serial.println("pick3: move shoulder");
  moveSpeed(shoulder, SPick3a, speed);
  setCurrent(shoulder, SPick3a);  //set joint current positionto final value
  delay(pauseTime);
  //Serial.println("pick3: move gripper");
  moveSpeed(gripper, GOpen, speed);
  setCurrent(gripper, GOpen);  //set joint current positionto final value
  delay(pauseTime);
  //Serial.println("pick3: move wrist");
  moveSpeed(wrist, WPick3, speed);
  setCurrent(wrist, WPick3);  //set joint current positionto final value
  delay(pauseTime);
  //Serial.println("pick3: move shoulder");
  moveSpeed(shoulder, SPick3b, speed);
  setCurrent(shoulder, SPick3b);  //set joint current positionto final value
  delay(pauseTime);
  //Serial.println("pick3: move gripper");
  moveSpeed(gripper, GClose, speed);
  setCurrent(gripper, GClose);  //set joint current positionto final value
  delay(pauseTime);
  //Serial.println("pick3: move shoulder");
  moveSpeed(shoulder, SUSHome, speed);
  setCurrent(shoulder, SUSHome);  //set joint current positionto final value
  delay(pauseTime);
  //Serial.println("pick3: move elbow");
  moveSpeed(elbow, EUSHome, speed);
  setCurrent(elbow, EUSHome);  //set joint current positionto final va
}

//drop off object at position 1
void place1() {
  Serial.println("drop at place 1");
  moveSpeed(base, BPlace1a, speed);  //pin 0
  delay(pauseTime);
  moveSpeed(shoulder, SPlace1a, speed);  //pin 4
  delay(pauseTime);
  moveSpeed(elbow, EPlace1a, speed);  //pin 4
  delay(pauseTime);
  moveSpeed(shoulder, SPlace1b, speed);  //pin 4
  delay(pauseTime);
  moveSpeed(shoulder, SPlace1b, speed);  //pin 4
  delay(pauseTime);
  moveSpeed(gripper, GOpen, speed);  //pin 1
  delay(pauseTime);
  moveSpeed(shoulder, SPlace1a, speed);  //pin 4
  delay(pauseTime);
  moveSpeed(base, BPlace1a, speed);  //pin 0
  delay(pauseTime);
  robotHoming();
}

//drop off object at position 2
void place2() {
  Serial.println("drop at place 2");
  moveSpeed(base, BPlace2a, speed);      //pin 0
  moveSpeed(shoulder, SPlace1a, speed);  //pin 4
  moveSpeed(elbow, EPlace2a, speed);     //pin 4
  moveSpeed(shoulder, SPlace2b, speed);  //pin 4
  moveSpeed(gripper, GOpen, speed);      //pin 1
  moveSpeed(shoulder, SPlace2b, speed);  //pin 4
  moveSpeed(gripper, GClose, speed);     //pin 1
  moveSpeed(shoulder, SPlace2a, speed);  //pin 4
  moveSpeed(base, BPlace2a, speed);      //pin 0
  robotHoming();
}

//drop off object at position 3
void place3() {
  Serial.println("drop at place 3");
  moveSpeed(base, BPlace3a, speed);  //pin 0
  delay(pauseTime);
  moveSpeed(shoulder, SPlace3a, speed);  //pin 4
  delay(pauseTime);
  moveSpeed(elbow, EPlace3a, speed);  //pin 4
  delay(pauseTime);
  moveSpeed(shoulder, SPlace3a, speed);  //pin 4
  delay(pauseTime);
  moveSpeed(shoulder, SPlace3b, speed);  //pin 4
  delay(pauseTime);
  moveSpeed(gripper, GOpen, speed);  //pin 1
  delay(pauseTime);
  moveSpeed(shoulder, SUSHome, speed);  //pin 4
  delay(pauseTime);
  moveSpeed(base, BUSHome, speed);  //pin 0
  delay(pauseTime);
  robotHoming();
}

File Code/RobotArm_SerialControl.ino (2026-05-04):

/*************************************************** 
CAB 2/2/26 - Modified for Serial Control
Robot Arm SERVO CONTROL
5 DOF Robot (base - 0, shoulder - 4, elbow - 3, wrist - 2, gripper - 1)
Input format: servo_pin microseconds (e.g. "0 1500")
 ****************************************************/

#include <Wire.h>
#include <Adafruit_PWMServoDriver.h>

Adafruit_PWMServoDriver pwm = Adafruit_PWMServoDriver();

#define SERVO_FREQ 50
#define baudrate 9600
#define oscFreq 27000000
#define numOfservo 5

// servo pin mapping
#define base 0
#define shoulder 4
#define elbow 3
#define wrist 2
#define gripper 1

// min/max limits (microseconds)
const uint16_t servoMin[] = { 600, 600, 800, 1000, 1000 };   // pin 0,1,2,3,4
const uint16_t servoMax[] = { 1800, 1300, 2000, 2000, 1800 }; // pin 0,1,2,3,4
//these are override later for testing purpose


void setup() {
  Serial.begin(baudrate);
  pwm.begin();
  pwm.setOscillatorFrequency(oscFreq);
  pwm.setPWMFreq(SERVO_FREQ);
  delay(1000);

  Serial.println("=== Robot Arm Serial Control ===");
  Serial.println("Format: pin microseconds");
  Serial.println("Example: 0 1500");
  Serial.println("Servo mapping:");
  Serial.println("  0 = base     (600-1800)");
  Serial.println("  1 = gripper  (600-1300)");
  Serial.println("  2 = wrist    (800-2000)");
  Serial.println("  3 = elbow    (1000-2000)");
  Serial.println("  4 = shoulder (1000-1800)");
  Serial.println("Ready.");
}

void loop() { 
  if (Serial.available()) {
    int pin = Serial.parseInt();
    int us = Serial.parseInt();

    // clear leftover newline
    while (Serial.available() && Serial.read() != '\n');

    if (pin < 0 || pin > 4) {
      Serial.print("Invalid pin: ");
      Serial.println(pin);
      return;
    }



    pwm.writeMicroseconds(pin, us);
    Serial.print("Pin ");
    Serial.print(pin);
    Serial.print(" -> ");
    Serial.print(us);
    Serial.println(" us");
  }
}

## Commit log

2026-05-04 inital commit
    [BaseHalf.stl, BaseHalf2.stl, Base_Ring.stl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]
2026-05-04 Added CAD files for the jig
    [Object_Jig.stl, Object_Jig_V2b.stl, Object_Jig_V3.stl]
2026-05-05 uploaded a couple specs file
    [Base_Ring.SLDDRW, Base_Ring.SLDPRT, Forearm.SLDDRW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]
2026-05-05 synced files fro MERL repo
    [BaseHalf2.3mf, Base_Ring.SLDDRW, ForeArm_Set.stl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]
